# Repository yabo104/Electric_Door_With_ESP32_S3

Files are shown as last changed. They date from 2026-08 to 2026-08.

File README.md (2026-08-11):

# Controlador de Portón — ESP32-S3

Controlador electrónico para automatizar la apertura y cierre de un portón residencial, con
firmware propio (ESP32-S3) y placa controladora diseñada a medida (KiCad).

Mueve el motor mediante dos relevos (sentido) y un TRIAC (potencia, por ángulo de fase
sincronizado al cruce por cero de la red), lee finales de carrera y un sensor de efecto Hall para
detectar movimiento/atasco, y decodifica un control remoto RF 433MHz.

## Estado actual

**Funcional en hardware real** — validado de punta a punta en un portón físico:

- Apertura y cierre con un solo botón del control remoto, con inversión de sentido y detención
  parcial (doble pulsación) para dejar pasar personas o vehículos sin abrir del todo.
- Interlock de seguridad: nunca ambos relevos activos a la vez, el motor siempre se detiene antes
  de invertir sentido.
- Detección de atasco por ausencia de pulsos del sensor de movimiento, con estado de falla y
  reset manual por un botón dedicado.
- Disparo del TRIAC por ángulo de fase, sincronizado al cruce por cero de la red — hoy en un
  **nivel de potencia fijo**, calibrado empíricamente en el portón real (ver *Limitaciones*).
- Indicador LED (encendido en movimiento, parpadeo al confirmar cada final de carrera) y un
  contador de pulsos por trayecto, pensado como base para una futura calibración de recorrido.
- Sin Wi-Fi ni Bluetooth: los dos radios se apagan explícitamente al arrancar.

### Limitaciones conocidas

- **Sin arranque/parada suaves todavía.** El disparo por ángulo de fase está implementado y
  funcionando, pero corre a potencia constante — la rampa gradual (arranque suave) quedó
  pospuesta: en las pruebas, disparar muy cerca del cruce por cero no enganchaba el TRIAC de
  forma confiable con este motor (carga inductiva), y la rampa pasaba por esa zona. La parada
  sigue siendo instantánea.
- El `timeout` de detección de atasco sigue en un valor ajustado empíricamente, no derivado
  analíticamente.
- El diseño de la placa (carpeta de KiCad) está en proceso de renombrado; los archivos de
  fabricación (gerbers/BOM) pueden no reflejar la última revisión del esquemático.

## Estructura del repositorio

- **`Firmware_Porton/`** — firmware, proyecto [PlatformIO](https://platformio.org/) (entorno
  `esp32-s3-devkitc-1`, framework Arduino).
- **`PCB_Door_Controller/`** — diseño de la placa controladora en KiCad.
- **`Docs/`** — datasheets y referencias de los componentes usados (driver TRIAC, convertidor
  DC-DC, módulo de alimentación).
- **`bitacora/`** — documentación de continuidad del proyecto (decisiones, arquitectura,
  histórico de sesiones de desarrollo) bajo el marco [stele](https://github.com/emezav/stele).

## Hardware

| Componente | Detalle |
| --- | --- |
| Módulo | ESP32-S3-WROOM-1U-N8R8 |
| Motor | AC 110V, fase partida (con capacitor de arranque) |
| Potencia | TRIAC BT138-800, disparo por ángulo de fase sincronizado a cruce por cero |
| Sentido | 2 relevos (interlock por software: nunca ambos activos) |
| Posición | 2 finales de carrera (reed switch) + sensor de efecto Hall |
| Control remoto | Receptor RF 433MHz (decodificado externamente, el ESP32-S3 lee canales digitales) |

## Arranque de desarrollo

```bash
cd Firmware_Porton
pio run                              # compilar
pio run -t upload --upload-port COMx # cargar a la placa
pio device monitor -p COMx -b 115200 # monitor serie (o el USB CDC nativo del ESP32-S3)
```

## Licencia

Sin definir todavía.

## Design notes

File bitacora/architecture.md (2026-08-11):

# architecture.md — Firmware_Porton

> Mapa de módulos y **patrones reutilizables** de este producto. Objetivo: que ningún agente
> tenga que releer el fuente para redescubrir un patrón ya entendido. Se **lee** al inicio de
> cualquier sesión que toque esta área y se **actualiza** al cerrar si se descubre un patrón
> nuevo.
>
> Frontera: aquí va *cómo está organizado el producto* (estructura + patrones). Las *trampas
> puntuales* van en `memory.md`; las *decisiones de producto* en `requirements.md`.
>
> Este proyecto tiene dos productos con estructura propia: el firmware (este archivo) y la placa
> controladora en KiCad (`PCB_puerta/` — en proceso de rename, ver `latest.md`).

## Stack

- C++ sobre framework **Arduino**, gestionado con **PlatformIO** (`Firmware_Porton/platformio.ini`).
- Build: `pio run` (desde `Firmware_Porton/`). Carga: `pio run -t upload`. Monitor:
  `pio device monitor -b 115200` (por USB CDC nativo del ESP32-S3, ver `platformio.ini`).

## Estructura de módulos

- `Firmware_Porton/platformio.ini` — entorno `esp32-s3-devkitc-1`, framework `arduino`, USB CDC
  habilitado desde el arranque (`ARDUINO_USB_MODE`/`ARDUINO_USB_CDC_ON_BOOT`).
- `Firmware_Porton/include/porton.h` — pines, tiempos de la máquina de estados (`#define`, todos
  en milisegundos) y prototipos públicos de `porton.cpp`.
- `Firmware_Porton/src/porton.cpp` — toda la lógica: inicialización, interlock de salidas de
  potencia, máquina de estados del portón, y la interfaz de pruebas por `Serial`. El detalle de
  funciones internas (`static`, no expuestas en el header) está comentado en el propio archivo.
- `Firmware_Porton/src/main.cpp` — `setup()`/`loop()`, delgado: inicializa, lee `Serial` si hay
  dato, y llama a `procesarComandoSerial()` + `actualizarEstadoPuerta()` en cada iteración.
- `Firmware_Porton/lib/`, `Firmware_Porton/test/` — carpetas estándar de PlatformIO, vacías por
  ahora.

## Patrones reutilizables ⭐

- **Interlock de salidas de potencia centralizado** — `seleccionarSentido(sentido)` en
  `src/porton.cpp` es el **único** punto del código que escribe `RELAY_OP`/`RELAY_CL`; siempre
  escribe los dos pines juntos, así que "ambos relevos activos a la vez" es estructuralmente
  imposible, no una convención a recordar. `detenerMotor()` corta `TRIGGER` primero y después
  llama a `seleccionarSentido(0)`. **Cualquier código nuevo que necesite mover el motor debe pasar
  por estas dos funciones, nunca por `digitalWrite` directo a los relevos/TRIGGER.**
- **Máquina de estados no bloqueante, con `millis()`** — `actualizarEstadoPuerta()`, sobre el enum
  `EstadoPuerta` (`DETENIDA`, `ABRIENDO`, `CERRANDO`, `ERROR`). Sin `while()`/`delay()` largos: los
  tiempos de asentamiento (`RELAY_SETTLE_MS`), de parada antes de invertir sentido
  (`REVERSE_STOP_MS`) y de timeout de atasco (`ENCODER_TIMEOUT_MS`) se miden comparando
  `millis()` contra un timestamp guardado, nunca bloqueando el `loop()`. Ver `requirements.md` §3.
- **Botón por flanco, no por nivel** — `botonD0Presionado()`/`botonResetPresionado()` solo
  disparan en la transición de no-presionado a presionado (con antirrebote), así que mantener el
  botón apretado no genera comandos repetidos. Cada botón tiene su propio estado de flanco/
  antirrebote — no se comparten, porque son semánticamente independientes (`D0` opera, el reset
  en `D2` solo reconoce una falla) y podrían presionarse casi a la vez.
- **Reset de falla como botón dedicado, no como gesto** — la salida de `ERROR` usa un pin físico
  aparte (`D2`) en vez de una pulsación larga del mismo botón de operar. Más simple de
  implementar (sin temporizar "cuánto es largo") y más seguro: una pulsación normal de `D0` nunca
  puede sacar de `ERROR` por accidente. Ver `requirements.md` §3/§4.
- **Pulsación única vs. doble durante el movimiento** — `manejarPulsacionEnMovimiento()`
  centraliza la decisión: una sola pulsación de `D0` programa una reversa segura (detiene,
  espera `REVERSE_STOP_MS`, invierte); una segunda pulsación dentro de `DOBLE_PULSACION_MS`
  cancela esa reversa y deja el portón donde está (apertura/cierre parcial). Es la misma función
  para los dos casos donde puede llegar la segunda pulsación (todavía en movimiento, o ya
  detenido esperando la reversa) — evita duplicar la lógica de "es doble o no".
- **Interfaz de comandos por Serial** — `procesarComandoSerial()`, un switch sobre caracteres
  ASCII. Reusa `seleccionarSentido()`/`detenerMotor()` en vez de escribir los pines de potencia
  por su cuenta, así el interlock también aplica en modo de prueba manual.
- **Disparo del TRIAC por ángulo de fase, con dos `esp_timer` en cascada** — `isrZcross()` (ISR
  real de `ZCROSS`, con antirrebote) arma `timerDisparo` con el retardo de fase actual
  (`delayDisparoActualUS`); su callback (`onDisparoTriac`) pulsa `TRIGGER` y arma `timerPulso`
  para soltarlo tras `PULSO_TRIAC_US`. Ninguna ISR hace trabajo pesado: solo lee una variable y
  arma un temporizador. `actualizarRampa()` (llamada desde `manejarMovimiento()`, fuera de
  cualquier ISR) es la única que **calcula** el retardo objetivo, interpolando con `millis()` —
  mismo patrón no bloqueante que el resto de la máquina de estados. Ver `requirements.md` §5.
- **Cancelar temporizadores pendientes al detener** — `detenerMotor()` llama `esp_timer_stop()`
  sobre `timerDisparo` antes de forzar `TRIGGER` a `HIGH`, para que no quede un disparo de fase
  ya programado que dispare el gate después de haber decidido parar. Mismo principio que "cortar
  `TRIGGER` antes de liberar los relevos" — parar significa parar todo, no solo la salida visible.
- **Contador de posición relativa (suma/resta según sentido)** — el contador de trayecto
  (`contadorTrayecto`, `requirements.md` §6) no cuenta pulsos crudos: compara el sentido actual
  (`doorStd`) contra el sentido con el que arrancó el trayecto (`sentidoTrayecto`) en cada pulso
  de `isrEncA2()`, sumando si coinciden y restando si no. Es el mismo patrón que usaría cualquier
  odómetro relativo sin posición absoluta — reutilizable si en el futuro hace falta estimar
  posición en otro contexto del proyecto.
- **Máquina de fases para efectos no bloqueantes cortos** — el parpadeo del LED
  (`actualizarParpadeoLed()`, `requirements.md` §7) usa un patrón chico de estados (`0` inactivo,
  `1` pausa, `2` encendido) con su propio timestamp, revisado cada iteración desde
  `actualizarEstadoPuerta()`. Mismo enfoque no bloqueante que el resto del código; sirve de
  plantilla para cualquier otra señal temporizada corta que se necesite más adelante (no hace
  falta un RTOS task ni un `esp_timer` para esto).

## Flujos clave

1. **Arranque:** `main.cpp:setup()` → `inicializarPines()` apaga WiFi/Bluetooth (`apagarRadios()`,
   `requirements.md` §8), deja relevos, `TRIGGER` y `LED` en su estado seguro/apagado, arma las
   interrupciones de encoder (`ENCA` y `ENCA2`, `CHANGE`) y de `ZCROSS` (`RISING`), crea los dos
   `esp_timer` del disparo del TRIAC, y abre `Serial`.
2. **Ciclo principal:** `main.cpp:loop()` → si hay dato en `Serial`, lo guarda en `comando` →
   `procesarComandoSerial()` → `actualizarEstadoPuerta()` (que además revisa el botón de reset y
   el parpadeo del LED en cada vuelta, antes del switch por estado).
3. **Apertura/cierre:** en `DETENIDA`, un flanco de `D0` decide sentido según la posición real
   (`FC_OPEN`/`FC_CLOSE`, o la última llegada confirmada si ninguno está activo —
   `requirements.md` §4) → si el origen es un final de carrera confirmado, arma el contador de
   trayecto (§6) → `iniciarMovimiento()` activa el relevo y enciende el LED fijo → tras
   `RELAY_SETTLE_MS` se habilita el TRIAC a potencia fija (`POTENCIA_MOTOR_PCT`, sin rampa por
   ahora — `requirements.md` §5) → en movimiento se vigilan fin de carrera de destino, timeout de
   encoder (atasco) y un nuevo flanco de `D0` (pide reversa o, si es la segunda pulsación dentro
   de `DOBLE_PULSACION_MS`, detiene y se queda a medio camino) → al llegar al fin de carrera,
   `detenerMotor()` (instantáneo), se guarda la llegada confirmada, se reporta el trayecto si era
   válido, y arranca el parpadeo del LED (§7).
4. **Atasco:** sin pulsos de `ENCA`/`ENCA2` durante `ENCODER_TIMEOUT_MS` con el TRIAC ya activo →
   `detenerMotor()` + `ERROR` (invalida el trayecto en curso). Única salida: un flanco de `D2`,
   que vuelve a `DETENIDA` sin reintento automático (ver `requirements.md` §3).

## Brecha conocida / pendiente

- **Parada suave y arranque suave "de verdad" (con rampa).** El release (sesión 008) corre a
  potencia fija — ver `requirements.md` §5 para el porqué (enganche inconsistente del TRIAC cerca
  del cruce por cero con esta carga inductiva). El código de la rampa
  (`RAMPA_ARRANQUE_MS`/`actualizarRampa()`) sigue en `porton.cpp` sin usar. Retomar ambas cosas
  queda pospuesto a una sesión futura, con calibración de recorrido por conteo de pulsos (§6)
  como paso previo — a especificar por el usuario.
- **`ESP_TIMER_ISR` no disponible en esta build** — los dos `esp_timer` del disparo del TRIAC
  corren en dispatch `ESP_TIMER_TASK` (por defecto), no en una ISR real; puede haber más jitter
  del ideal en el ángulo de disparo. No impidió que el release funcionara en el portón real. Ver
  `memory.md`.

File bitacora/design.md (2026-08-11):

# design.md — Decisiones y principios generales del proyecto

> **Por qué `Controlador_Porton` es como es**, a gran escala. Estable, se lee para orientarse y
> rara vez cambia. Frontera: aquí van *principios y apuestas grandes transversales*; las *specs y
> decisiones por feature* van en `requirements.md`; los *patrones de código* en
> `architecture.md`; las *trampas de código* en `memory.md`. Tope objetivo ~200 líneas: si una
> decisión crece, se extrae a su tema de `requirements.md` y aquí queda 1-3 líneas + link.

## Norte

Controlador electrónico para automatizar la apertura y cierre de un portón, con su propio
firmware y placa controladora diseñada a medida. A futuro, este proyecto forma parte de un pool
de proyectos open-source del usuario, pensados como referencia de trabajos realizados.

## Principios de diseño (no negociables)

- **Un hogar por dato** — cada hecho vive en un solo documento; los demás apuntan.
- **Fail-safe en las salidas de potencia** — relevos y disparo de TRIAC arrancan en `HIGH`
  (desactivados) en `setup()`; ADAPTAR si esto deja de ser cierto al cambiar el hardware.
- ADAPTAR: agregar aquí otros tenets durables (p. ej. tiempos de seguridad, comportamiento ante
  falla de sensor, requisitos normativos si aplica) a medida que se decidan.

## Restricciones y no-negociables

- **Wi-Fi y Bluetooth apagados activamente** (`apagarRadios()`, sesión 008) — el ESP32-S3 los
  tiene disponibles pero el proyecto no los usa; se descartó además un modo de bajo consumo
  (deep sleep) para ahorrar energía/calor, porque el equipo está alimentado de red, no a batería
  (detalle en Decisiones estructurales más abajo). A futuro: Bluetooth para controlar el portón
  desde una app móvil (no hay diseño de ese protocolo todavía — cuando se aborde, hay que volver
  a habilitar el radio explícitamente, y documentar el protocolo en `requirements.md`).
- **Idioma de la documentación (decisión del usuario, sesión 005):** durante el desarrollo activo
  se mantiene en español (es lo que ya hay y lo que configura `stele.config.md`). **Cuando el
  proyecto se dé por terminado**, se traduce todo a inglés, porque el destino es un pool de
  proyectos open-source de referencia. No es un cambio a aplicar ahora — es una tarea de cierre
  de proyecto (traducir `bitacora/`, comentarios de código, `README` si se agrega uno, etc.),
  a recordar cuando se llegue a esa etapa.
- ADAPTAR: agregar otros límites (normativos, presupuesto, requisitos de seguridad eléctrica al
  operar TRIAC/relevos de línea) a medida que se decidan.

## Decisiones estructurales (ADR-lite)

> Decisiones grandes y transversales. Formato corto y fechado; el detalle va a `requirements.md`.

### 2026-08-07 — Firmware migrado de sketch `.ino` a proyecto PlatformIO

- **Contexto:** el firmware vivía como un único `Firmware_Porton.ino` (Arduino IDE), sin
  separación entre inicialización, lógica de puerta y manejo de comandos.
- **Decisión:** reestructurar `Firmware_Porton/` como proyecto PlatformIO (`platformio.ini`,
  `src/main.cpp`, `src/porton.cpp`, `include/porton.h`), entorno `esp32-s3-devkitc-1`.
- **Alternativas descartadas:** mantener el `.ino` (Arduino IDE) — descartado porque el proyecto
  pasa a usar PlatformIO como herramienta de build/flash a partir de ahora.
- **Consecuencias / detalle:** ver `architecture.md`.

### 2026-08-08 — Máquina de estados del portón: interlock de seguridad + no bloqueante

- **Contexto:** el firmware original (plantilla de pruebas) no garantizaba por diseño que los dos
  relevos nunca estuvieran activos juntos, invertía sentido con `delay()` bloqueantes, y no tenía
  forma de detectar un atasco del motor.
- **Decisión:** interlock de relevos centralizado en una sola función (`seleccionarSentido()`,
  ver `architecture.md`), máquina de estados no bloqueante basada en `millis()`, y detección de
  atasco por timeout de pulsos del encoder (`ENCA` por interrupción). El TRIAC se trata como
  interruptor todo/nada (sin `ZCROSS`) hasta una sesión futura. Detalle en `requirements.md` §3/§4.
- **Alternativas descartadas:** mantener el diseño con `while()`/`delay()` bloqueantes — se
  descartó porque impide medir timeouts (atasco) y responder a `Serial` mientras la puerta se
  mueve.
- **Consecuencias / detalle:** ver `architecture.md` → Patrones reutilizables y Brecha conocida.

### 2026-08-08 — Validación en hardware real: control remoto D0/D2 y recuperación de ERROR

- **Contexto:** primera sesión con la placa física conectada. Se confirmó en hardware que abrir/
  cerrar, finales de carrera, interlock de relevos, TRIAC a máxima potencia y detección de atasco
  funcionan. Aparecieron dos problemas de hardware (no de firmware): `ENCA`/`ENCB` con pull-ups
  defectuosos, y el conteo de `ZCROSS` con ruido de umbral (parcialmente corregido por software).
  El usuario pidió además: separar el botón de operar del de reset de falla, una forma de detener
  el portón a medio camino (apertura parcial para personas/motos), y una política de salida de
  `ERROR`.
- **Decisión:** `D0` concentra todo el control normal (abrir/cerrar/invertir/detener parcial);
  `D2` es un botón dedicado, exclusivo, para salir de `ERROR` — nunca reintento automático tras
  un atasco (mismo criterio que UL 325 para fallas de obstrucción: la salida de una falla es una
  acción humana deliberada). Detección de atasco migrada a `ENCA2` (sensor Hall en `GPIO44`),
  confirmada limpia en banco, en paralelo con `ENCA` por si se repara. Detalle completo en
  `requirements.md` §3/§4, patrones en `architecture.md`.
- **Alternativas descartadas:** pulsación larga del mismo botón (`D0`) para resetear `ERROR` — se
  descartó por un botón dedicado (`D2`): más simple de implementar y evita que una pulsación
  normal saque de `ERROR` por accidente. Reversa automática alejándose de la obstrucción al
  entrar en `ERROR` — se descartó por ahora: sin sensor de obstrucción dedicado, no hay forma de
  saber hacia dónde es seguro moverse.
- **Consecuencias / detalle:** ver `requirements.md` §3/§4 y `architecture.md`.

### 2026-08-08 — Arranque suave del TRIAC: alcance acotado a solo arranque

- **Contexto:** el portón toma velocidad y golpea fuerte contra el tope al cerrar, con riesgo
  para los engranajes. El usuario pidió arranque y parada suaves por ángulo de fase del TRIAC.
  Antes de tocar código se armó un plan (vía plan mode) y se lo discutió con el usuario.
- **Decisión:** acotar esta ronda a **solo arranque suave**, para validar primero si el mecanismo
  de disparo por fase regula bien la potencia real (confirmado el TRIAC: `BT138-800`, pulso de
  gate de 200us). La parada sigue siendo instantánea. Parada suave con zona de desaceleración
  necesita conteo de pulsos de recorrido completo y un modo de calibración — el usuario lo va a
  especificar en una sesión futura, no se improvisa ahora. Detalle en `requirements.md` §5.
- **Alternativas descartadas:** implementar arranque y parada juntos en la misma ronda — se
  descartó porque la parada depende de una pieza no diseñada todavía (calibración de recorrido
  por pulsos de `ENCA2`, con un solo canal de encoder — no hay dirección, solo conteo).
- **Estado al cierre de la sesión 007:** implementado y subido a la placa, pero **sin confirmar
  que el arranque suave se perciba en el motor real** — el usuario no notó diferencia en la
  primera prueba. Pendiente diagnóstico con osciloscopio (sesión futura) antes de dar la
  funcionalidad por buena. Ver `requirements.md` §5 y `memory.md` para el detalle técnico y las
  dos hipótesis abiertas (bug vs. limitación física del motor de inducción).
- **Consecuencias / detalle:** ver `requirements.md` §5 y `architecture.md`.

### 2026-08-11 — TRIAC: release en potencia fija; posición inferida por última llegada confirmada

- **Contexto:** sesión larga de pruebas en el portón físico real (no solo el motor en banco).
  Salieron a la luz dos problemas que la sesión 007 no había podido ver: (1) la rampa de arranque
  suave pasaba por ángulos de disparo cercanos al cruce por cero donde el TRIAC no engancha de
  forma confiable con esta carga inductiva, generando paradas falsas por "atasco"; (2) por
  inercia del motor, el imán de un fin de carrera puede rebasar el sensor al frenar, dejando
  momentáneamente "ningún fin de carrera activo" aunque el portón esté efectivamente en esa
  posición — el firmware volvía a intentar moverse hacia el mismo tope.
- **Decisión:** cerrar el release con el TRIAC en **potencia fija** (85%, calibrada probando
  varios niveles en el portón real — ver `requirements.md` §5), la rampa de arranque suave
  pospuesta. Y agregar `ultimaLlegadaConfirmada`: cuando ningún fin de carrera está activo, el
  sentido se decide contra la última llegada confirmada de verdad, no siempre "cierra por
  defecto" (`requirements.md` §4). También se agregaron, a pedido del usuario: contador de
  trayecto por pulsos de `ENCA2` (§6, para datos de una futura calibración de recorrido) e
  indicador LED (§7, pensado para la instalación final sin acceso al Serial).
- **Alternativas descartadas:** insistir con la rampa ajustando solo los tiempos — se descartó
  porque el problema no era de tiempos sino de que la rampa pasaba por una zona de disparo donde
  el TRIAC no engancha bien; había que resolver eso primero (queda como base para retomar la
  rampa más adelante).
- **Consecuencias / detalle:** ver `requirements.md` §4/§5/§6/§7, patrones en `architecture.md`,
  hallazgos técnicos en `memory.md`.

(Repetir por decisión. Las que dejan de ser relevantes se podan; su rastro queda en el historial.)

## Glosario

- **Portón** — la puerta/reja automatizada que controla este sistema.
- **FC_OPEN / FC_CLOSE** — finales de carrera (reed switch) que indican portón totalmente abierto
  / cerrado.
- **D0-D3** — canales ya decodificados del receptor RF 433MHz de los controles remotos. `D0` =
  control normal (abrir/cerrar/invertir/detener parcial); `D2` = reset de `ERROR` únicamente;
  `D1`/`D3` sin rol asignado.
- **TRIGGER** — señal de disparo del TRIAC, sincronizada con `ZCROSS` (cruce por cero de la AC)
  por ángulo de fase. **Release actual:** ángulo fijo (potencia constante, sin rampa) — ver
  `requirements.md` §5. El TRIAC regula la **potencia** entregada al motor; no decide el sentido
  de giro (eso lo hacen los relevos).
- **RELAY_OP / RELAY_CL** — relevos que eligen el **sentido** de giro del motor (qué terminal de
  control queda energizado), no la potencia.
- **Motor de fase partida (110VAC)** — motor con un terminal común y dos terminales de control,
  con un capacitor (33µF/400V) entre ambos que produce el desfase necesario para girar en un
  sentido u otro según cuál terminal se energiza.
- **ENCA / ENCB** — canales en cuadratura del encoder del motor. Tienen un problema real de
  hardware (pull-up del circuito de entrada) y hoy no aportan pulsos.
- **ENCA2** — sensor de efecto Hall alternativo (`GPIO44`), confirmado funcionando en banco: es
  la fuente real de detección de atasco hoy, en paralelo con `ENCA` por si se repara. También
  alimenta el contador de trayecto (`requirements.md` §6).
- **Última llegada confirmada** — el último fin de carrera que el firmware vio activarse de
  verdad (no inferido). Decide el sentido del próximo movimiento cuando ningún fin de carrera
  está activo en el momento de la pulsación (`requirements.md` §4).
- ADAPTAR: agregar términos de dominio adicionales según surjan (p. ej. nombre/modelo del
  operador de portón, protocolo del control remoto).

## Mapa de documentación

Dónde vive cada tipo de información: ver `AGENTS.md` → "Dónde vive cada cosa" (no duplicar aquí).

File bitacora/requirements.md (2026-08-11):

# requirements.md — Qué hace el producto (specs, contratos, decisiones por feature)

> **Fuente de verdad del producto**: specs, contratos de API, modelo de datos, decisiones por
> feature, contexto de negocio detallado. Es lo que perdura y comparten todos los agentes y
> sesiones. Frontera: los *principios y apuestas grandes transversales* van en `design.md`; los
> *patrones de código* en `architecture.md`; las *trampas de código* en `memory.md`.
>
> **Estructura:** una sección `§` por decisión o feature, **autocontenida**. Este archivo se lee
> con `grep` y por rango, nunca entero. **Umbral de extracción: ~50 líneas** — por encima, la
> decisión se mueve a `bitacora/temas/<TEMA>.md` y aquí queda un resumen de 2-3 líneas + link.

## Cómo usar este archivo

- **Antes de implementar**, `grep -n` la sección relevante y lee solo esa parte.
- **Toda decisión** de producto/arquitectura/integración/negocio que deba perdurar se documenta
  aquí *en el momento en que se toma*.

## § Índice de decisiones

- §1 — Interfaz de comandos por Serial (pruebas de banco)
- §2 — Contrato de hardware: sistema de potencia y pines ESP32-S3
- §3 — Máquina de estados del portón (segura, no bloqueante)
- §4 — Política del control remoto (D0/D1)
- §5 — Disparo del TRIAC por ángulo de fase (release: potencia fija, sin rampa)
- §6 — Contador de trayecto (pulsos de `ENCA2`)
- §7 — Indicador LED
- §8 — Radios WiFi/Bluetooth apagadas (sin deep sleep)

### §1 — Interfaz de comandos por Serial (pruebas de banco)

- **Contrato:** `Firmware_Porton` expone por `Serial` (USB CDC nativo del ESP32-S3, 115200
  baudios) una interfaz de un solo carácter para pruebas manuales, manejada en
  `procesarComandoSerial()` (`Firmware_Porton/src/porton.cpp`):
  - `0` — parpadea el LED.
  - `1` — activa el relevo de apertura, **sin habilitar el TRIAC** (no mueve el motor).
  - `2` — activa el relevo de cierre, **sin habilitar el TRIAC**.
  - `3` — detiene todo (relevos + TRIAC), vía la misma función `detenerMotor()` que usa la
    máquina de estados.
  - `4` — imprime por Serial el estado de las entradas `D0`-`D3`.
  - `5` — fuerza `TRIGGER` en `HIGH` (TRIAC apagado).
  - `6` — fuerza `TRIGGER` en `LOW` (TRIAC encendido, máxima potencia).
  - `7` — limpia el comando pendiente (no-op).
  - Los comandos `1`/`2` reusan `seleccionarSentido()`, la misma función que usa la máquina de
    estados automática — así el interlock de "nunca ambos relevos activos" aplica también en modo
    de prueba manual.
  - Esta interfaz **no** reemplaza a la máquina de estados de la puerta (`actualizarEstadoPuerta()`),
    que corre en paralelo cada iteración del `loop()`. Si se usan comandos manuales mientras la
    puerta está en movimiento automático, pueden interferir entre sí (es una interfaz de banco,
    no pensada para correr junto con operación autónoma).
- **Por qué:** pensada para validar cableado/hardware de banco antes de operar el portón de forma
  autónoma. No es un protocolo pensado para integrarse con otro sistema.

### §2 — Contrato de hardware: sistema de potencia y pines ESP32-S3

- **Qué es:** motor AC 110V de fase partida (común + 2 terminales de control + capacitor 33µF/
  400V entre ellos), 2 relevos que eligen el sentido, 1 TRIAC que regula la potencia (sincronizado
  a `ZCROSS`), encoder de 2 canales para detectar movimiento/dirección, 2 finales de carrera *reed
  switch*, receptor RF 433MHz que expone 4 canales digitales (`D0`-`D3`). Tabla completa de pines
  ESP32-S3 con tipo/polaridad de cada señal.
- **Por qué se extrajo:** contrato largo (tabla de 13 pines + descripción de sistema) y es la
  referencia autoritativa antes de escribir cualquier lógica de firmware nueva.
- Detalle completo, con la brecha entre este contrato y lo que el firmware actual ya implementa:
  [`bitacora/temas/hardware-esp32-s3.md`](./temas/hardware-esp32-s3.md).

### §3 — Máquina de estados del portón (segura, no bloqueante)

- **Estados** (`EstadoPuerta` en `include/porton.h`): `DETENIDA`, `ABRIENDO`, `CERRANDO`, `ERROR`.
  Reemplaza al diseño anterior (`STOP`/`WAITING` separados) — `DETENIDA` cubre tanto el arranque
  como el reposo entre movimientos.
- **Reglas de seguridad no negociables** (pedidas por el usuario, sesión 004):
  1. **Nunca ambos relevos activos a la vez.** Se garantiza por construcción:
     `seleccionarSentido()` escribe siempre los dos pines juntos (uno `LOW`, el otro `HIGH`, o los
     dos `HIGH`); ningún otro punto del código escribe `RELAY_OP`/`RELAY_CL` por separado.
  2. **El motor se detiene ante cualquier cambio de sentido** — nunca se invierte "en caliente".
     Al detectar un pedido de reversa en movimiento, se llama `detenerMotor()` (corta `TRIGGER`
     primero, después libera los relevos) y se guarda el sentido pedido en `sentidoPendiente`; el
     nuevo sentido recién arranca tras `REVERSE_STOP_MS` (500 ms) detenido.
  3. **La potencia (TRIAC) se habilita después del relevo**, no junto con él:
     `RELAY_SETTLE_MS` (100 ms) entre elegir sentido y encender `TRIGGER`. Evita conmutar el
     relevo con el motor ya energizado.
- **TRIAC con disparo por ángulo de fase, sincronizado a `ZCROSS`, desde la sesión 007** — ver §5.
  Reemplaza al diseño anterior (interruptor todo/nada).
- **Detección de atasco vía encoder — confirmada en hardware real (sesión 006):** una
  interrupción actualiza un timestamp (`ultimoPulsoEncoderISR`); si el TRIAC lleva más de
  `ENCODER_TIMEOUT_MS` (2000 ms — ajustado varias veces por el usuario durante las pruebas de la
  sesión 008 en el portón real; sigue marcado `TEMPORAL` en el código, no hay un valor "final"
  derivado analíticamente) activo sin ningún pulso, se detiene el motor y se pasa a `ERROR`. Dos
  fuentes en paralelo alimentan el mismo timestamp: `ENCA` (con un problema de hardware conocido —
  pull-up del circuito de entrada — hoy no aporta pulsos) y `ENCA2`, un sensor Hall en `GPIO44`
  que sí funciona (confirmado: 0 pulsos con el motor quieto, pulsos reales con el motor girando).
  Si se arregla el hardware de `ENCA`, vuelve a sumar sin más cambios de código.
- **Salida de `ERROR` — implementada y confirmada en hardware real (sesión 006):** botón
  dedicado (`D2`, ver §4) saca de `ERROR` y vuelve a `DETENIDA` "como recién arrancado" — el
  siguiente `D0` decide el sentido por la posición real de los finales de carrera. **Sin
  reintento automático**, a propósito: un atasco puede ser una obstrucción real, y reintentar
  por temporizador movería el motor otra vez sin que nadie lo haya verificado (mismo criterio
  que usan los estándares de portones automáticos tipo UL 325 para fallas de obstrucción). Una
  reversa automática alejándose de la obstrucción queda como posible mejora futura, pospuesta
  hasta tener un sensor de obstrucción dedicado.
- **No bloqueante:** se eliminaron los `while()`/`delay()` largos que había en el diseño anterior
  dentro de la máquina de estados (bloqueaban `loop()` y hubieran roto el timeout de atasco). Los
  tiempos (`RELAY_SETTLE_MS`, `REVERSE_STOP_MS`, `ENCODER_TIMEOUT_MS`) se miden con `millis()`
  sin bloquear.

### §4 — Política del control remoto (D0 mueve, D2 resetea fallas)

> Confirmado en hardware real, sesión 006. `D1`/`D3` están cableados en la tarjeta pero sin rol
> asignado por ahora.

- **`D0` — control normal (abrir/cerrar/invertir/detener parcial).** Detección por flanco, no
  por nivel: un botón mantenido presionado genera un solo comando, no uno por iteración del
  `loop()`. Con antirrebote (`BOTON_DEBOUNCE_MS`, 80 ms).
  - **El sentido se decide por la posición real** (finales de carrera), no por el último
    movimiento hecho: portón en el fin de carrera de **abierto** → `D0` **cierra**; en el de
    **cerrado** → `D0` **abre**. Se evalúa en cada pulsación, no solo al arrancar.
  - **Posición intermedia (ningún fin de carrera activo) — corregido en la sesión 008:** ya no
    es siempre "por defecto cierra". El firmware recuerda la última llegada **confirmada**
    (`ultimaLlegadaConfirmada`, en `porton.cpp`) y decide el sentido contrario a esa. Esto cubre
    un caso real encontrado en el portón físico: por inercia del motor, el imán del fin de
    carrera puede rebasar el sensor al frenar, y el switch se desactiva de nuevo justo después de
    haber llegado — sin este ajuste, el firmware volvía a intentar cerrar (o abrir) contra el
    tope mecánico ya alcanzado. Solo si **nunca** hubo una llegada confirmada (arranque en frío,
    posición realmente desconocida) se usa el default original: cierra.
  - **Una pulsación de `D0` durante el movimiento invierte el sentido** — nunca en caliente:
    detiene, espera `REVERSE_STOP_MS` (500 ms), recién ahí arranca en el sentido contrario.
  - **Dos pulsaciones de `D0` dentro de `DOBLE_PULSACION_MS` (2000 ms) durante el movimiento:
    detiene y se queda a medio camino, sin invertir.** Pensado para apertura/cierre parcial (dejar
    pasar una persona o una moto sin abrir del todo). Implementado en
    `manejarPulsacionEnMovimiento()` — una segunda pulsación que caiga dentro de la ventana de
    `REVERSE_STOP_MS` (mientras espera para iniciar la reversa) también cuenta como "doble".
- **`D2` — reset manual de `ERROR` únicamente.** No mueve el portón. Ver §3 para la política de
  por qué no hay reintento automático tras un atasco.
- **`D1`/`D3` sin uso.** Se leen igualmente en el comando de prueba `4` (`requirements.md` §1)
  pero no participan de la lógica automática.

### §5 — Disparo del TRIAC por ángulo de fase (release: potencia fija, sin rampa)

> Mecanismo implementado en la sesión 007 (plan discutido y aprobado con el usuario antes de tocar
> código). **Motivo original:** el portón tomaba velocidad y golpeaba fuerte contra el tope al
> cerrar, con riesgo de dañar los engranajes. **Decisión de alcance para el release (sesión 008,
> con el usuario):** dejar el TRIAC en **potencia fija** (sin la rampa de arranque suave) — ver el
> porqué más abajo.

- **Mecanismo (sin cambios desde la sesión 007):** `ZCROSS` es una interrupción real (no solo
  diagnóstico). En cada cruce por cero válido (con antirrebote, `ZCROSS_DEBOUNCE_US`), si el TRIAC
  está activo, arma un `esp_timer` con el retardo de fase actual (`delayDisparoActualUS`); al
  vencer, pulsa `TRIGGER` (gate del TRIAC `BT138-800`) por `PULSO_TRIAC_US` con un segundo
  `esp_timer`. `PULSO_TRIAC_US` subió de 200 a 500µs en la sesión 008: un pulso más largo ayuda a
  enganchar con esta carga inductiva.
- **La rampa de arranque suave (interpolar `DISPARO_US_MIN` → `DISPARO_US_MAX` durante
  `RAMPA_ARRANQUE_MS`) quedó DESACTIVADA para el release.** Motivo, encontrado en pruebas en banco
  con el portón real (sesión 008): disparar demasiado cerca del cruce por cero (potencias
  cercanas al 100%) no siempre engancha el TRIAC con esta carga inductiva — al 100% exacto
  (~6,5° desde el cruce) el motor directamente no se movía. La rampa original pasaba por esa zona
  marginal al principio de cada arranque, y eso generaba paradas falsas por "atasco" (§3): el
  enganche inconsistente ciclo a ciclo genera pulsos de torque irregulares, no una rampa suave de
  potencia creciente.
- **Solución para el release: potencia fija, calibrada empíricamente.** `POTENCIA_MOTOR_PCT` (hoy
  85%, en `porton.h`) fija `DISPARO_US_MIN = DISPARO_US_MAX` — el TRIAC dispara al mismo ángulo de
  fase durante todo el movimiento, sin rampa. Es una interpolación **lineal en tiempo** entre
  `DISPARO_US_MAX` (100%) y `SEMICICLO_US` (0%), no un porcentaje exacto de potencia RMS (esa
  relación es curva), pero sirve como perilla monótona para ajustar a mano si hace falta.
  Historial de pruebas que llevaron al 85%: 100% no movía el motor; 90% y 95% sí lo movían pero
  daban `ERROR` falso en tramos del recorrido con más esfuerzo mecánico; 85% (con el pulso de gate
  ya en 500µs) fue el primer nivel que movió el portón de punta a punta sin falsos atascos.
- **La parada sigue siendo instantánea** — sin rampa de bajada, sin cambios en esta sesión.
- **Arranque suave real (con rampa) queda pospuesto**, ahora con un piso de potencia fiable
  (85%, pulso de 500µs) como punto de partida en vez de los valores originales sin probar. El
  código de la rampa (`RAMPA_ARRANQUE_MS`, `actualizarRampa()`) se deja en `porton.cpp` sin usar,
  para no rehacerlo desde cero cuando se retome.
- **Detalle de hallazgos técnicos y gotchas de esta implementación:** `memory.md`.

### §6 — Contador de trayecto (pulsos de `ENCA2`)

> Agregado en la sesión 008 a pedido del usuario, para poder revisar si el recorrido completo del
> portón da una cantidad de pulsos de `ENCA2` medianamente consistente entre corridas — dato de
> entrada para una futura calibración de recorrido (parada suave con zona de desaceleración,
> pospuesta, ver §5).

- **Solo es válido entre dos finales de carrera confirmados.** Arranca en 0 únicamente cuando un
  movimiento empieza con un fin de carrera activo en el origen (abierta→cierra o cerrada→abre) —
  **no** desde una posición intermedia (incluida la inferida por `ultimaLlegadaConfirmada`, §4):
  ahí no hay un punto de partida medido, solo asumido, y contaminaría la comparación entre
  corridas.
- **Suma en el sentido del trayecto, resta en el sentido contrario.** Cada pulso de `ENCA2`
  incrementa el contador si el sentido actual coincide con el que tenía el trayecto al arrancar, y
  lo decrementa si no (hubo una reversa) — así el contador siempre refleja la distancia neta
  recorrida desde el origen confirmado, aunque haya idas y vueltas en el medio.
- **Se invalida en silencio (decisión del usuario) si el trayecto se interrumpe** antes de llegar
  al destino: detenido parcial (doble pulsación) o `ERROR` (atasco). No se imprime nada — solo se
  reportan los recorridos completos, que son el dato comparable.
- **Al llegar al fin de carrera de destino**, si el trayecto era válido, imprime por Serial
  `[TRAYECTO] completo, sentido=…, pulsos=…`.

### §7 — Indicador LED

> Agregado en la sesión 008 a pedido del usuario, pensando en la instalación final del portón
> (sin acceso directo al Serial).

- **Encendido fijo mientras el motor está en movimiento** (`ABRIENDO`/`CERRANDO`), apagado el
  resto del tiempo — centralizado en `iniciarMovimiento()`/`detenerMotor()`, no hay otro punto del
  código que escriba `LED` para la operación automática.
- **Parpadeo al detectar el fin de carrera de destino** (confirma que se detectó el imán) —
  **no** en detenido parcial ni en `ERROR`, para no dar una señal engañosa. Secuencia de dos fases,
  no bloqueante: pausa apagada (`LED_PAUSA_PARPADEO_MS`, 100ms) y luego encendido
  (`LED_PARPADEO_MS`, 150ms). La pausa es necesaria: sin ella, el parpadeo arranca desde el mismo
  "encendido" que ya tenía por el movimiento, y el flanco no se distingue a simple vista (bug
  real encontrado en la primera versión, sesión 008).
- **Prioridad estricta:** siempre se llama primero a `detenerMotor()` (corte de salidas,
  instantáneo) y recién después se dispara el parpadeo — nunca al revés.

### §8 — Radios WiFi/Bluetooth apagadas (sin deep sleep)

> Decisión de la sesión 008, a partir de una pregunta del usuario sobre bajo consumo/calor del
> ESP32-S3. Detalle completo de la discusión en `design.md` → Decisiones estructurales.

- **`WiFi.mode(WIFI_OFF)` + `btStop()`** en `inicializarPines()` (`apagarRadios()`,
  `porton.cpp`) — el proyecto no usa ninguno de los dos radios, así que apagarlos evita consumo/
  calor/interferencia sin costo funcional.
- **Se descartó el deep sleep** (que el usuario planteó primero) porque este equipo está
  alimentado de red, no a batería — el ahorro de energía no justifica el costo: perder toda la
  RAM en cada ciclo de sueño (hay que reconstruir el estado desde memoria RTC), la latencia de
  arranque en frío en cada despertar, que el USB CDC (el `Serial` que se usó para depurar toda
  esta sesión) se cae mientras duerme, y verificar con osciloscopio que los relevos/TRIAC no
  flotan durante la transición de sueño/despertar antes de confiar en él con 110VAC de por medio.
- **Costo de la librería WiFi:** aunque solo se llama para apagarla, enlazarla infla el binario
  notablemente (Flash ~8%→20%, RAM ~6%→13% en esta build) — sigue sobrando margen de sobra, pero
  vale la pena saberlo si en el futuro el espacio se vuelve ajustado.

## Modelo de datos

ADAPTAR: no aplica lógica de datos persistentes todavía; el firmware es puramente reactivo sobre
entradas digitales. Si se agrega persistencia (p. ej. posición del portón, configuración por
NVS/EEPROM), documentar aquí el modelo.

## Contratos de API / integración

ADAPTAR: hoy no hay integración de red (Wi-Fi/BLE/MQTT, etc.). Si se agrega, documentar aquí el
contrato (endpoints, payloads, autenticación).

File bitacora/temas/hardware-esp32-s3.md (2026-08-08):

# Tema: Contrato de hardware — sistema de potencia y pines ESP32-S3

> Extraído de `requirements.md` §2 (superó el umbral de ~50 líneas). Fuente: descripción del
> usuario, sesión `003` (`2026-08-08`). Es el **contrato autoritativo** de qué hace cada pin y
> cómo está compuesto el sistema de potencia — el firmware debe respetarlo.

## Sistema de potencia (motor del portón)

- **Motor AC de 110V, fase partida, un solo motor.** Tres terminales: uno **común** y dos de
  **control de giro** (uno por sentido). Entre los dos terminales de control hay un
  **capacitor de arranque/marcha de 33 µF / 400 V** — es lo que da el desfase para que el motor
  gire en un sentido u otro según cuál terminal de control se energiza.
- **Dos relevos (`RELAY_OP`, `RELAY_CL`) conmutan cuál terminal de control queda activo** — deciden
  el **sentido** de giro (abrir/cerrar), no la potencia entregada.
- **Un TRIAC regula la potencia** entregada al motor (fase controlada, sincronizada con el cruce
  por cero de la AC vía `ZCROSS`). Es el elemento que controla **cuánta** potencia recibe el
  motor (p. ej. arranque suave, limitar torque), independiente del sentido que ya fijaron los
  relevos.
- **Encoder de dos canales (`ENCA`, `ENCB`) en el eje del motor** — pulsos en cuadratura: permiten
  saber si el motor **está girando o no**, y en qué **dirección** (por el desfase entre A y B).
  Es la única realimentación de movimiento real (sin él, el firmware no puede distinguir "el
  relevo está activado" de "el motor efectivamente se está moviendo").
- **Dos finales de carrera tipo *reed switch*** (`FC_OPEN`, `FC_CLOSE`) — un imán solidario a la
  parte móvil acciona el reed switch correspondiente al llegar a cada extremo del recorrido.
- **Receptor RF 433 MHz** para los controles remotos — decodifica la señal de aire y expone el
  resultado como hasta 4 líneas digitales (`D0`-`D3`) hacia el ESP32-S3; el ESP32-S3 no decodifica
  RF directamente, solo lee esas salidas ya decodificadas.

## Pines ESP32-S3 (contrato)

| GPIO | Nombre | Tipo | Descripción |
| --- | --- | --- | --- |
| 2 | `LED` | Salida / digital | LED piloto. **Activo en `LOW`** (nivel 0 = encendido). |
| 3 | `ZCROSS` | Entrada / interrupción | Cruce por cero de la AC: pulso en **alto** en cada cruce. Pensado para disparar por interrupción, no por polling (es una señal de temporización). |
| 9 | `D3` | Entrada / digital / RF | Canal decodificado del receptor RF. Activo en **alto**. |
| 10 | `D2` | Entrada / digital / RF | Ídem. |
| 11 | `D1` | Entrada / digital / RF | Ídem. |
| 12 | `D0` | Entrada / digital / RF | Ídem. |
| 13 | `ENCA` | Entrada / interrupción / encoder | Canal A del encoder de movimiento del motor. |
| 14 | `ENCB` | Entrada / interrupción / encoder | Canal B del encoder de movimiento del motor. |
| 15 | `FC_OPEN` | Entrada / interrupción / final de carrera | **Normalmente en alto**; flanco de bajada cuando el imán llega (portón abierto). |
| 16 | `FC_CLOSE` | Entrada / interrupción / final de carrera | **Normalmente en alto**; flanco de bajada cuando el imán llega (portón cerrado). |
| 21 | `TRIGGER` | Salida / digital / disparo TRIAC | Dispara el TRIAC con nivel **bajo**. |
| 38 | `RELAY_OP` | Salida / digital | Activa el relevo de apertura con nivel **bajo**. |
| 39 | `RELAY_CL` | Salida / digital | Activa el relevo de cierre con nivel **bajo**. |

## Consistencia con el firmware actual (`Firmware_Porton/`)

Confirmado contra `include/porton.h` / `src/porton.cpp`:

- Polaridades activas en `LOW` de `RELAY_OP`, `RELAY_CL`, `TRIGGER`, y activo en alto de `D0`-`D3`
  y de los finales de carrera vía `INPUT_PULLUP` (`!digitalRead(FC_OPEN)` = detectado) — **ya
  coinciden** con el código existente.
- **Nuevo dato, no reflejado aún en el firmware:** polaridad de `LED` (activo en `LOW`) — el
  código actual ya arranca en `HIGH` (apagado) en `inicializarPines()`, consistente por
  casualidad de diseño, no porque el firmware lo supiera documentado.
- **Brecha real:** `ZCROSS`, `ENCA`/`ENCB` y `FC_OPEN`/`FC_CLOSE` están pensados como fuentes de
  **interrupción**, pero el firmware actual solo hace `pinMode(..., INPUT[_PULLUP])` y lee
  `FC_OPEN`/`FC_CLOSE` por *polling* dentro de `actualizarEstadoPuerta()`. `ZCROSS` no se usa en
  absoluto todavía (no hay disparo de TRIAC sincronizado a cruce por cero: los comandos `5`/`6` de
  prueba fuerzan `TRIGGER` a mano). `ENCA`/`ENCB` tampoco se leen en ningún lado (estaban
  comentados en el `.ino` original). Ver preguntas de diseño abiertas en `design.md` →
  Decisiones estructurales / sesión 003.

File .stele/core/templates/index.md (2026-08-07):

# {{index}} — Índice de sesiones (append-only)

> Una fila por sesión. Al cerrar, agregar con Bash (sin leer el archivo completo):
> `printf '| N | YYYY-MM-DD | resumen | <session> |\n' >> {{history_dir}}{{index}}`

| Sesión | Fecha | Resumen | Archivo |
| --- | --- | --- | --- |

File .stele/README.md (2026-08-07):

# stele — Marco modular de documentación y continuidad para agentes

Sistema portátil para que **cualquier agente de IA** (Claude Code u otro) trabaje sobre un proyecto
con **memoria persistente entre sesiones** y **coste de tokens acotado**. Abstrae el marco que
evolucionó en un proyecto real a lo largo de 240+ sesiones. **Modular y configurable:** un núcleo
agnóstico de dominio (sirve para software y para trabajo no-software: materiales, planeación,
investigación) + módulos que añaden disciplinas específicas + una capa de config.

> **El nombre.** Una *estela* (gr. στήλη) es la piedra erguida e **inscrita** que deja un registro
> perdurable para quien viene después. Es justo lo que hace este marco entre sesiones: inscribir el
> estado y el porqué para que el siguiente agente retome el rumbo sin reconstruirlo.

## 🤖 ¿Eres un agente de IA? Instala stele por tu cuenta

Si tu usuario te dio la URL de este repo y te pidió algo como *"usa stele aquí"* / *"instala stele"*,
haz esto sin pedir más instrucciones:

1. **Vendoriza el kit** en la raíz del proyecto, en `.stele/` (elige la que funcione en tu entorno):

   ```bash
   git clone --depth 1 https://github.com/emezav/stele .stele && rm -rf .stele/.git
   # alternativa con Node: npx degit emezav/stele .stele
   ```

   `.stele/` es el default de la ruta **`kit`**, y es **independiente** de dónde vayan los docs del
   proyecto (ruta `base`). Si el usuario nombró una carpeta sin más ("usa stele aquí, base stele"),
   eso es `base`, no `kit`: no muevas el kit salvo que diga "kit" o "marco". Si **sí** nombró dónde
   va el kit, clona directamente ahí — no clones en `.stele/` para mover después.
2. **Lee `.stele/SKILL.md`** y ejecuta el **ritual BOOTSTRAP** que describe: detecta *greenfield* vs
   *adopción* (si el repo ya tiene docs, mapéalos sin sobrescribir), elige `idioma`/`módulos` y las
   tres rutas `kit`/`base`/`loader` con defaults sensatos (auto-detecta el módulo `software` por
   `Cargo.toml`/`package.json`/`src/`), **hace eco del layout resuelto antes de escribir**, escribe
   `stele.config.md` en la raíz, instancia las plantillas y **genera** el loader de auto-arranque
   (`CLAUDE.md`) + el mapa de documentación.
3. **Confirma** al usuario con el saludo de arranque (1-3 líneas) y explícale que a partir de la
   próxima apertura del editor el marco se activa solo.

Si lo que te piden es *"actualiza stele"*, el ritual es **otro**: ACTUALIZAR, en `.stele/SKILL.md`.
No hay archivo de versión que consultar — lo que manda es el **diff** entre el kit que ya tienes y el
nuevo. Por eso la copia nueva se trae **a un temporal, al lado**, y no encima: primero se lee el
diff, y solo después se sustituye el kit.

No improvises la estructura: la fuente de verdad de rituales es `.stele/SKILL.md`, y el *por qué* y
las fronteras están en `.stele/guide.md`. Léelos antes de escribir nada.

## Arquitectura (tres capas)

- **Núcleo** (`core/`) — roles + rituales + principios, agnósticos. Se define sobre **ids de rol
  estables**, no sobre nombres de archivo. Roles en `core/roles.md`; plantillas en `core/templates/`.
- **Módulos** (`modules/<nombre>/`) — paquetes de roles + disciplinas. Incluido: `software`
  (añade `specs`/`architecture`/`gotchas`/`effort` + convenciones + la regla del checkpoint antes
  del primer archivo de código). Un proyecto no-software no lo activa.
- **Config** (`stele.config.md`, en la raíz del proyecto destino) — **fuente única** que enlaza
  `rol → nombre`, activa módulos, fija toggles/presupuestos/wording/idioma, declara las **tres
  rutas** — `kit` (dónde vive el marco, default `.stele`), `base` (dónde viven tus docs, default
  `.`) y `loader` (el auto-arranque, default `CLAUDE.md`) — y la **persistencia** (`git` ·
  `ninguna` · `comando`: cómo se vuelve durable el trabajo al cerrar). De aquí se **generan** el
  auto-arranque y el mapa de documentación.

## Qué contiene esta carpeta

- **`SKILL.md`** — hoja operativa: rituales *bootstrap · abrir · checkpoint · cerrar · auditar ·
  contrastar · remitir · actualizar · config*, el mapa de documentación (cómo se genera) y la
  convención de tokens. Léelo primero.
- **`guide.md`** — el *por qué*: pilares, arquitectura de capas, roles y fronteras, presupuestos.
  Referencia; se lee una vez.
- **`core/`** — `roles.md` (roles del núcleo, fuente del mapa derivado) + `templates/` (plantillas
  por rol: `entry`, `charter`, `protocol`, `state`, `handover`, `index`, `session`, `audit`,
  `correspondence`, `letter`, `autostart`, `config`).
- **`modules/software/`** — `module.md` (manifiesto), `roles.md`, `conventions.md` y `templates/`
  (`specs`, `architecture`, `gotchas`, `effort`).
- **`buzon.md`** — correspondencia de stele hacia quien usa el marco. **Baja sola** con cada
  actualización (no hay servicio ni cuenta: el kit se copia, y las cartas viajan con él). Contiene
  preguntas que solo pueden responder proyectos reales. Se contesta con el ritual REMITIR, por el
  canal que prefieras — copiar y pegar basta.

Las plantillas se escriben **por rol** con tokens `{{rol}}`; bootstrap/`config` los resuelven a los
nombres del manifiesto (los docs instanciados quedan con nombres concretos y legibles).

## Instalar en un proyecto (vendorizado)

El marco es **markdown puro** (sin runtime): se instala **vendorizando** una copia del kit dentro
del proyecto, en la ruta `kit` (default `.stele/`). La copia es la fuente para el agente; para
actualizar se sustituye entera con el ritual **ACTUALIZAR** (que primero saca el diff y luego
reconcilia tu instancia) — por eso **tus docs (`base`) nunca pueden vivir dentro del kit**.

1. Trae el kit a `<proyecto>/.stele/` (elige uno):

   ```bash
   # opción a — degit (sin historia git, recomendado)
   npx degit emezav/stele .stele
   # opción b — clonar y copiar
   git clone --depth 1 git@github.com:emezav/stele.git /tmp/stele && mkdir -p .stele && cp -r /tmp/stele/. .stele/ && rm -rf .stele/.git
   ```

2. Pide al agente **"bootstrapea la stele"** (ritual BOOTSTRAP en `.stele/SKILL.md`): detecta
   greenfield vs adopción, elige `idioma`/`módulos` y las tres rutas (con defaults), te muestra el
   layout resuelto, escribe `stele.config.md` en la raíz, instancia las plantillas bajo `base`, y
   genera el loader de auto-arranque + el mapa-doc.
3. El **loader** (ruta `loader`, por defecto `CLAUDE.md`) es la activación automática: el agente lo
   carga al iniciar la sesión, hace `@`-import del set de arranque y saluda con 1-3 líneas (señal de
   que arrancó). Cámbialo si tu agente espera otro nombre (`AGENTS.md`, etc.).
4. (Opcional, Claude Code) para que `/stele` recuerde los rituales bajo demanda, vendoriza el kit
   directamente en `.claude/skills/stele` y pon `kit = .claude/skills/stele`: una sola copia, que se
   actualiza en un solo sitio. Si ya lo tienes en `.stele/`, `cp -r .stele .claude/skills/stele`
   también funciona, pero deja dos copias que hay que mantener sincronizadas a mano.

Para cambiar nombres, activar/desactivar módulos o mover cualquiera de las tres rutas después:
ritual **CONFIG** (no editar los derivados a mano).

**Layouts con nombre:** hay cuatro atajos para las combinaciones habituales de `kit` + `base` —
`default`, `agrupado`, `docs` y `skill`. Puedes pedir uno por su nombre ("bootstrapea con layout
agrupado"), y bootstrap te dice cuál resolvió antes de escribir nada. La tabla con los valores de
cada uno está en `SKILL.md` → "Layouts con nombre"; no son un parámetro que se guarde, solo una
forma corta de nombrar dos rutas.

> Detalle de rituales y plantillas: `SKILL.md`. Fundamentos, capas y fronteras: `guide.md`.
> El historial de diseño del marco vive en `git log`, no en el kit: todo lo que se vendoriza es lo
> que un agente necesita para trabajar.

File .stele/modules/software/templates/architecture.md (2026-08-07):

# {{architecture}} — <área/producto>

> Mapa de módulos y **patrones reutilizables** de este producto (normalmente un codebase). Objetivo:
> que ningún agente tenga que releer el fuente para redescubrir un patrón ya entendido. Se **lee** al
> inicio de cualquier sesión que toque esta área y se **actualiza** al cerrar si se descubre un patrón
> nuevo. Uno por producto (monorepo: uno por paquete relevante).
>
> Frontera: aquí va *cómo está organizado el producto* (estructura + patrones). Las *trampas
> puntuales* van en `{{gotchas}}`; las *decisiones de producto* en `{{specs}}`.

## Stack
ADAPTAR: lenguaje, framework, librerías clave, cómo se construye/corre.

## Estructura de módulos
ADAPTAR: directorios/paquetes y su responsabilidad, en una línea cada uno.

## Patrones reutilizables ⭐
ADAPTAR: los patrones que se repiten y conviene conocer antes de escribir. Por patrón:
- **<Nombre del patrón>** — qué resuelve, dónde está la implementación de referencia
  (`ruta/archivo.ext`), y cómo usarlo. (p. ej. capa de acceso a datos, manejo de auth,
  componente de tabla estándar, proxy/BFF, manejo de errores.)

## Flujos clave
ADAPTAR: 1-3 flujos de punta a punta que un agente nuevo debe entender (p. ej. "petición →
proxy → API → DB", "evento en tiempo real", "build/deploy").

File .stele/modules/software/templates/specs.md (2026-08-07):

# {{specs}} — Qué hace el producto (specs, contratos, decisiones por feature)

> **Fuente de verdad del producto**: specs, contratos de API, modelo de datos, decisiones por
> feature, contexto de negocio detallado. Es lo que perdura y comparten todos los agentes y
> sesiones. Frontera: los *principios y apuestas grandes transversales* van en `{{charter}}`;
> los *patrones de código* en `{{architecture}}`; las *trampas de código* en `{{gotchas}}`.
>
> **Estructura:** una sección `§` por decisión o feature, **autocontenida**. Este archivo se lee con
> `grep` y por rango, nunca entero: lo que importa es que cada sección sea corta por sí misma, no el
> tamaño del total. **Umbral de extracción: ~50 líneas** — por encima, la decisión se mueve a un
> archivo de tema (`{{specs_dir}}<TEMA>.md`) y aquí queda un resumen de 2-3 líneas + link. Un tema
> que supera ~600-800 líneas se divide en sub-temas.

## Cómo usar este archivo

- **Antes de implementar**, `grep -n` la sección relevante y lee solo esa parte (no el archivo completo).
- **Toda decisión** de producto/arquitectura/integración/negocio que deba perdurar se documenta
  aquí *en el momento en que se toma* — si no está aquí, es invisible para otros agentes y sesiones.

## § Índice de decisiones

ADAPTAR: una sección por decisión/feature, autocontenida y por debajo de ~50 líneas; con link al
tema cuando la haya superado.

### §1 — <Área / feature>

- **<Decisión / contrato / regla>** — el qué, el porqué y lo que se descartó. Si esta sección pasa
  de ~50 líneas, se extrae: `{{specs_dir}}<TEMA>.md`.

## Modelo de datos

ADAPTAR: entidades clave y relaciones (o link al tema). Identificadores canónicos y qué NO confundir.

## Contratos de API / integración

ADAPTAR: endpoints/convenciones estables (o link al tema por recurso).

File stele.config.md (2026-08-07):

# stele.config — Configuración del marco

> Fuente única de la configuración de ESTE proyecto. La editas a mano o con el ritual `config`
> (`.stele/SKILL.md`). El **auto-arranque** y el **mapa de documentación** se GENERAN de aquí —
> no los edites por separado. Todo lo accionable va en **tablas**; la prosa solo explica.
>
> **Contrato de parseo:** los headers `##` son secciones canónicas y fijas, en este orden:
> `Meta` · `Rutas` · `Nombres` · `Features` · `Presupuestos` · `Wording de rituales`. Se
> referencian por posición, no por su texto. En cada tabla, col1 = clave, col2 = valor; columnas
> y filas extra se ignoran. `—` en un nombre = rol desactivado. Fila ausente = default del
> rol/feature (ver `.stele/core/roles.md` y `.stele/modules/<mód>/`). Al aplicar un cambio,
> `config` reescribe la tabla afectada **completa** y regenera los derivados.

## Meta

| Parámetro | Valor |
| --- | --- |
| idioma | es |
| módulos | software |
| persistencia | git |
| persistencia_cmd | — |
| kit_origen | `https://github.com/emezav/stele` |
| remitente | — |
| remitente_publico | — |

## Rutas

| Ruta | Valor | Qué es |
| --- | --- | --- |
| kit | .stele | El marco vendorizado (`SKILL.md`, `guide.md`, `core/`, `modules/`). |
| base | bitacora | Raíz de los docs instanciados (layout `agrupado`). |
| loader | CLAUDE.md | Loader de auto-arranque, siempre en la raíz. GENERADO. |

## Nombres (rol → archivo)

| Rol | Archivo | Origen |
| --- | --- | --- |
| entry | AGENTS.md | núcleo |
| charter | design.md | núcleo |
| protocol | protocol.md | núcleo |
| state | latest.md | núcleo |
| handover | handover.md | núcleo |
| index | index.md | núcleo |
| history_dir | history/ | núcleo |
| session | sesion-{NNN}-{YYYY-MM-DD}.md | núcleo |
| audit | audit.md | núcleo |
| correspondence | cartas.md | núcleo |
| letter | carta-{NNN}-{YYYY-MM-DD}.md | núcleo |
| correspondence_dir | correspondencia/ | núcleo |
| artifacts_dir | artefactos/ | núcleo |
| gotchas | memory.md | software |
| specs | requirements.md | software |
| specs_dir | temas/ | software |
| architecture | architecture.md | software |
| effort | esfuerzo.md | software |

## Features (toggles)

| Feature | Valor |
| --- | --- |
| effort_log | on |
| effort_unit | horas-ingeniero |
| session_greeting | on |
| audit_log | on |
| audit_every_n_sessions | 10 |
| correspondence_log | on |

## Presupuestos

| Doc (rol) | Máx. líneas |
| --- | --- |
| state | 100 |
| handover | 50 |

## Wording de rituales

| Ritual | Parámetro | Texto |
| --- | --- | --- |
| checkpoint | trigger | antes de la primera edición de código |
| abrir | saludo | 1-3 líneas: última sesión + estado handover + próximo paso |

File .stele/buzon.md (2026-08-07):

# buzon.md — Correspondencia de stele hacia quien usa el marco

> **Qué es.** El buzón de salida del kit. Como ACTUALIZAR se trae el árbol entero, **estas cartas
> bajan solas** con cada actualización: no hay servicio, ni red, ni cuenta que crear. Tu agente lo lee
> al actualizar (tabla de zonas de impacto, `SKILL.md`) y te dice si hay algo para ti.
>
> **Qué hacer con una carta.** Si te interesa, contéstala con el ritual **REMITIR** (`SKILL.md`) y
> mándala por donde quieras — pegarla en la sesión de tu agente, un correo, un issue. Copiar y pegar
> basta; no hace falta saber git ni tener cuenta en ninguna parte. Si la contestas o te mueve a hacer
> algo, **archiva tu copia**: este buzón se cura, y lo de aquí desaparece.
>
> **Regla de curación (importante).** Este archivo es **carga pública y permanente**: viaja a cada
> copia del kit. Por eso se poda —una pregunta contestada se retira— y el rastro queda en `git log`.
> Mismo criterio que el resto del marco: lo histórico vive en la historia, no en el kit.
>
> **Sobre nombres.** Aquí no se nombra a nadie sin su permiso: un proyecto aparece por el `remitente`
> con el que firmó, o en anónimo. Y las cartas hablan de **ideas**, nunca de quien las tuvo.
>
> **El tachado rige también hacia aquí.** Lo que se publica en este buzón suele nacer de un informe que
> llegó **en privado**, y esos informes vienen llenos de tripas de quien los mandó: rutas internas,
> nombres de máquinas y servicios, datos de terceros. Contestar en público sin releer con esa lente
> **filtra lo que se contó en confianza**, y el seudónimo no protege de eso. Se tacha antes de bajar,
> igual que antes de subir.

---

## Carta 1 — Aviso: dos archivos del kit cambiaron de nombre

**De:** stele · **Para:** todo el que ya tuviera el kit · **Fecha:** 2026-08-07

**El caso.** El kit pasó a la regla *"minúscula por defecto; MAYÚSCULA solo donde la impone algo
externo"*. Sobreviven en mayúscula `README.md`, `LICENSE`, `CLAUDE.md`, `AGENTS.md` y `SKILL.md` — este
último **no** por GitHub sino por el layout `skill`, donde Claude Code busca ese nombre exacto.

Cambiaron dos: **`GUIDE.md` -> `guide.md`** y **`BUZON.md` -> `buzon.md`**.

**Lo que te afecta, y no lo cubre la tabla de zonas.** Si algún doc **tuyo** enlaza al kit por el
nombre viejo, ahora tienes una referencia colgada. La tabla dice que `guide.md` "se lee, no se migra",
lo cual es cierto para su contenido y **no dice nada de tus enlaces hacia él**. Compruébalo:

```bash
# acotado a TUS docs: sustituye <base> por tu ruta base (`.`, `docs`, `bitacora`…)
grep -rn "GUIDE\.md\|BUZON\.md" <base> --include="*.md"
```

**Acota el comando a tu `base` en vez de barrer desde la raíz**, y no es un detalle: el kit vive en un
directorio **oculto**, y las herramientas no coinciden en qué hacer con eso — `ripgrep` lo salta por
defecto, `grep -r` de GNU entra. Barriendo desde la raíz con GNU te salen las referencias **internas
del kit**, que están perfectamente bien, y parecen enlaces rotos.

Lo que salga dentro de tu `base` es tuyo y hay que corregirlo a mano. Y si estás en Windows, ojo: el
sistema de archivos no distingue mayúsculas, así que el enlace viejo **te sigue funcionando ahí** y se
romperá en el primer clon en Linux. Arréglalo igual.

**Qué NO demuestra este caso.** No sabemos cuántos adoptantes enlazan al kit por nombre; puede que
ninguno. El aviso cuesta menos que el silencio.

## Carta 2 — Qué se rechazó de los reportes de campo, y por qué

**De:** stele · **Para:** quien vaya a reportar algo · **Fecha:** 2026-08-07

Las **reglas** que salieron de los reportes ya están en el kit; lo que el kit no lleva son los
**descartes**, y son lo que más viaje ahorra. Tres, sin nombrar a nadie:

- **No se creó un módulo nuevo para los detectores de red.** La propuesta era razonable —puertos y
  servicios no son "software" en general, sino proyectos que operan servicios— pero aquí **un módulo
  es un paquete de roles**, y ese aporte no traía ninguno. Va condicionado dentro de `software`.
- **No se suben los presupuestos porque alguien los exceda.** Un tope que sube cada vez se convierte
  en decoración. Se decide: se poda con criterio, o se sube con `config` **después** de podar. Y un
  presupuesto no distingue *"el proyecto creció"* de *"el doc derivó de género"* — la pregunta *"¿qué
  sobra?"* es lo único que las separa.
- **No se finge privacidad en un buzón.** El kit se copia entero, así que no hay destinatarios ni
  entrega selectiva: un archivo con el nombre de alguien sería *algo que parece protegido sin
  estarlo*. Lo privado va por otro canal, que es el modo por defecto de todos modos.

**Y la regla que gobierna esto:** el **diagnóstico viaja, el remedio no**. Cuatro de cuatro reportes
llegaron con el diagnóstico correcto y el remedio equivocado o incompleto — no por torpeza, sino
porque quien reporta tiene el **caso** y el proyecto tiene el **contexto de diseño**. Escribe el caso;
la propuesta es la parte menos valiosa de tu carta y no hace falta traerla.

## Carta 3 — ¿Tu loader tenía contenido propio antes de adoptar stele?

**De:** stele · **Para:** cualquiera que haya adoptado el marco · **Fecha:** 2026-08-07

**El caso.** El marco tiene una regla dura, el *invariante 6*: si el archivo de auto-arranque
(`CLAUDE.md`, `AGENTS.md`, el que uses) **ya existía**, se **modifica** y no se recrea — el bloque del
marco va entre las marcas `STELE:INICIO` / `STELE:FIN` y **todo lo que quede fuera se conserva
íntegro**. La regla nació de un fallo real: en el primer bootstrap fuera del repo original, el ritual
tomó un `CLAUDE.md` escrito a mano por el nombre de un derivado y lo sobrescribió entero. Se perdió el
contenido.

**Lo que no podemos comprobar.** La mitad de esa regla sigue **sin probarse en campo**. Un proyecto
que ya actualizó nos confirmó que el bloque se porta bien, pero **no tenía nada fuera de las marcas**,
así que su caso no dice nada sobre la conservación de lo externo. Aquí tampoco podemos probarlo: este
repo genera su propio loader.

**Lo que preguntamos, y son dos preguntas distintas.** Si tu proyecto tenía un `CLAUDE.md` o un
`AGENTS.md` **escrito a mano antes** de adoptar el marco:

1. ¿Quedó texto tuyo **FUERA** de las marcas `STELE:INICIO`/`STELE:FIN`? Si es así: ¿sigue ahí
   íntegro tras el bootstrap y las actualizaciones? Y si se perdió algo, ¿qué ritual lo tocó?
2. ¿Tu texto propio acabó **DENTRO** de las marcas — porque al insertar el bloque se rodeó lo que ya
   había en vez de añadirlo aparte?

**La segunda es la que más nos importa, y la aprendimos tarde.** Al preguntar solo por la primera, un
proyecto nos contestó *"fuera de las marcas no tengo nada"* y dimos por hecho que su caso no servía.
No era así: su contenido preexistía, solo que **encerrado dentro**. Y ahí el invariante 6 no protege
nada, porque no hay nada fuera que conservar — todo lo propio está en la zona que el marco se autoriza
a reescribir. Es la situación más peligrosa de las tres y desde fuera se ve igual que un loader
generado de cero.

Si estás en ese caso: **marca tu bloque como `STELE:INICIO RICO` ahora**, antes de la próxima
actualización. Ahí la marca no es una comodidad — es lo único que se interpone.

**Qué NO nos sirve.** Si tu loader lo generó el bootstrap desde cero y nunca escribiste nada a mano,
tu caso no responde a ninguna de las dos. Hace falta un archivo que **preexistía**.

**Por qué te lo pedimos a ti.** Es una pregunta que el marco no puede contestarse solo: solo la
responde alguien que llegó con documentación propia. Y de esa respuesta depende una regla que hoy
protege datos que no podemos ver.

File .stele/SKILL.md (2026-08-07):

---
name: stele
description: >
  Marco modular y configurable de documentación y continuidad para trabajar en un proyecto a
  través de muchas sesiones sin perder contexto y con coste de tokens acotado. Sirve para software
  y para trabajo no-software (materiales, planeación, investigación). Úsalo al INICIAR una sesión
  (ponerse al día), al CERRAR (registro durable), antes de un cambio interrumpible (checkpoint),
  para AUDITAR la documentación (verificar que lo escrito sigue siendo cierto), para INICIALIZAR el
  marco en un proyecto (bootstrap), para ACTUALIZARLO a una versión nueva del kit (actualizar), o
  para ADAPTARLO (config: nombres, módulos, parámetros). Núcleo agnóstico + módulos (software) +
  config (stele.config.md).
---

# stele — rituales de sesión

> Hoja operativa. El *por qué* y las fronteras están en `guide.md` (leer una vez). Plantillas en
> `core/templates/` y `modules/<mód>/templates/`. Roles en `core/roles.md` y `modules/<mód>/roles.md`.
> Regla madre: **un hogar por dato; el estado se sobrescribe; el historial es append-only; lee poco
> al arrancar.** Los nombres de archivo salen del manifiesto `stele.config.md`.

## Mapa de documentación (GENERADO — consúltalo antes de leer/escribir)

El mapa "necesito X → tal archivo" **no se escribe a mano**: se genera en el doc `entry` desde los
`triggers` de los roles activos + el binding de la config. Regla de generación:

- **Roles activos** = roles del núcleo (`core/roles.md`) + roles de los módulos activos, menos los
  que tengan nombre `—` en la config.
- **Lista de arranque** = roles `startup: obligatorio`, ordenados por `order`, nombre resuelto
  (`{base}/[{history_dir}/]{nombre}`). El resto va a la nota "bajo demanda con grep".
- **Tabla de enrutamiento** = una fila `trigger → nombre` por cada rol activo.

Se regenera en `config` y al activar/desactivar módulos o renombrar. **Regla de oro anti-tokens:**
no leas un archivo entero "por si acaso"; usa el mapa y `grep -n` + lectura por rango.

## El punto inicial significa "maquinaria", y conviene decirlo

El kit vive en un directorio oculto (`.stele`, `.claude/skills/stele`) y tus documentos no. **Eso no
es casualidad: el punto marca lo que el marco se autoriza a sustituir entero.** Lo que empieza por
punto es reemplazable y no se edita a mano; lo que no, es tuyo y el marco no lo toca jamás.

Estaba en vigor desde el principio y nunca se había escrito, que es como una convención deja de
comunicar.

**Con un límite que hay que reconocer:** la convención del punto **es legible exactamente para quien
no la necesita**. Quien programa ya sabe que lo oculto es herramienta; quien no, no tiene por qué
saberlo — y es justo el público al que se le recomienda `agrupado`. Por eso declararla **no sustituye**
a que las dos carpetas se llamen distinto: lo acompaña.

**Consecuencia práctica que sorprende:** un directorio oculto **no lo tratan igual todas las
herramientas**. `ripgrep` y muchos buscadores lo saltan por defecto; `grep -r` de GNU entra. Así que
un mismo comando de barrido da resultados distintos según qué tenga instalado quien lo corre — y por
eso **todo comando que publiques debe acotar dónde busca** en vez de fiarse del default.

## Precedencia frente a los defaults del harness

**Dónde vive lo que produces en este proyecto lo decide el marco, no la herramienta que te ejecuta.**
Muchos harnesses inyectan un área de trabajo propia —scratchpad, memoria del agente, temporal de
subagente— y la marcan como prioritaria. Es un default razonable *para la herramienta*, y es el
equivocado *para el proyecto*: lo que se escribe ahí no lo ve el siguiente agente, no lo ve el humano,
y no queda en el registro. Ante conflicto, manda el mapa de documentación y el hogar de artefactos.

**El límite, y hay que respetarlo:** esta precedencia cubre **el destino de los archivos**. No alcanza
a las reglas de seguridad del harness, ni a cómo usa sus herramientas, ni a sus permisos. Una regla
que reclama más de lo que le toca se ignora entera, y con razón.

Esto no es una regla de estilo: es la que evita que el marco pierda en silencio. Ha hecho falta
escribirla dos veces por el mismo motivo — un default externo vació una regla del marco que nunca dijo
quién manda, y las dos veces lo descubrió una persona leyendo, no el mecanismo.

## Convención de tokens en plantillas

Las plantillas se escriben por **rol** y usan tokens que bootstrap/`config` resuelven a nombres:
`{{rol}}` → nombre del rol (p. ej. `{{state}}`→`latest.md`); `{{history_dir}}`, `{{specs_dir}}`,
`{{artifacts_dir}}` y `{{correspondence_dir}}` → **rutas** de los roles contenedores;
`{{budget:rol}}` → tope de líneas; `{{effort_unit}}` y
`{{checkpoint_trigger}}` → valores de Features/Wording; `{{kit}}` y `{{loader}}` → rutas
(sección Rutas). Los toggles como `session_greeting` **se consultan, no se interpolan**: no hay
token para ellos.
Los bloques marcados `<!-- GENERADO -->` los produce el marco, no se editan a mano.

**Toda ruta interpolada es relativa a la raíz del proyecto**, nunca al doc que la contiene: los
agentes operan con el CWD en la raíz y es lo que hace `grep`, así que el valor no depende de dónde
quedó cada archivo. De ahí dos reglas de composición:

- `{{kit}}` se escribe **sin `/` final** y se usa como `{{kit}}/SKILL.md`. **Con `kit = .` el prefijo
  colapsa**: `{{kit}}/SKILL.md` → `SKILL.md`, no `./SKILL.md`.
- Los **contenedores** (`{{history_dir}}`, `{{specs_dir}}`, `{{artifacts_dir}}`, `{{correspondence_dir}}`) resuelven **con `base` delante y con `/`
  final**, así que se concatenan directos, sin barra intermedia: `{{history_dir}}{{index}}` →
  `stele/history/index.md` con `base = stele`, y `history/index.md` con `base = .` (el prefijo
  colapsa igual que en `{{kit}}`). En el manifiesto el valor configurado es solo el nombre de la
  carpeta (`history/`); es el token el que le antepone `base` al resolverse.

Esto importa sobre todo en lo **ejecutable**. Un `printf '…' >> {{history_dir}}{{index}}` mal
compuesto no da error: crea el archivo que falta y deja el de verdad sin la fila.

**Dos clases de ruta, y no se resuelven igual** — confundirlas es lo que rompe enlaces al mover
`base`:

- **Ruta de comando** (`printf >> …`, `grep`, `git log --`): relativa a la **raíz del proyecto**,
  porque los agentes operan con el CWD ahí. Es la que producen los tokens.
- **Enlace Markdown clicable** (`[index.md](./index.md)`): relativo al **archivo que lo contiene**,
  porque así lo resuelve cualquier visor. Sobrevive a un cambio de `base` solo si su destino se mueve
  en el mismo bloque — que es el caso dentro de `{{history_dir}}`, y por eso el historial se mueve
  entero y no se reescribe. Un enlace que apunte **fuera** del bloque movido sí se rompe: revísalos
  al migrar.

## Las tres rutas: `kit` · `base` · `loader`

| Ruta | Default | Qué contiene | Quién la escribe |
| --- | --- | --- | --- |
| `kit` | `.stele` | El marco vendorizado. Maquinaria **reemplazable**. | Ritual ACTUALIZAR |
| `base` | `.` | Los docs instanciados (roles). Contenido **del proyecto**. | El agente, cada sesión |
| `loader` | `CLAUDE.md` | Auto-arranque, siempre en la raíz. GENERADO **por bloque**. | `bootstrap`/`config` |

**Invariantes** (validar en `bootstrap` y en `config`, antes de escribir):

1. `base` **nunca** dentro de `kit`: actualizar reemplaza el directorio del kit entero, y se llevaría
   los docs por delante. Violación = abortar. **Excepción: modo auto-hospedado** (`kit = .`), cuando
   el proyecto **es** el marco — el repo del kit. Ahí el kit no se vendoriza: se desarrolla en sitio
   y nunca se borra, así que la razón del invariante no aplica y `base` es por fuerza un
   subdirectorio suyo. En ese modo `base` debe ser un subdirectorio propio, nunca `.` (ver 2).
2. `kit` == `base` = abortar (misma razón, caso degenerado).
3. `kit` dentro de `base` (p. ej. `base = stele`, `kit = stele/.stele`) es legal pero **se avisa**:
   los `grep` del ritual de apertura empiezan a encontrar plantillas del marco como si fueran docs
   del proyecto.
4. El `loader` vive en la raíz y no puede colisionar con el nombre de un rol resuelto bajo `base`
   (con `base = .` y `loader = AGENTS.md` chocaría con `entry`). Colisión = abortar.
5. `stele.config.md` y el `loader` son las **dos anclas fijas de la raíz**: no siguen a `base`.
6. **Si el archivo del `loader` ya existe, se MODIFICA — nunca se crea de cero.** Su contenido es del
   usuario: se conserva íntegro y el bloque del marco se **inserta** entre las marcas
   `STELE:INICIO` / `STELE:FIN`. Solo ese bloque se reescribe después. Sobrescribir el archivo entero
   destruyó el `CLAUDE.md` de un proyecto real. Vale igual en `bootstrap` y en `config`.
   **Y si la marca de apertura dice `RICO`, ese bloque tampoco se reescribe entero:** el proyecto lo
   enriqueció con reglas propias, así que se porta el delta a mano. Vale en `config` igual que en
   `actualizar` — los dos rituales tocan ese bloque.

**El loader es derivado en parte, no desechable.** Lo generado es el bloque; el **archivo** puede ser
compartido con contenido del proyecto — muchos equipos ya tenían un `CLAUDE.md` o un `AGENTS.md`
escrito a mano antes de adoptar el marco. Se le aplica la misma regla de adopción que a cualquier doc
de rol: mapear y añadir, jamás reemplazar.

### Layouts con nombre (vocabulario, no parámetro)

Cuatro combinaciones de `kit` + `base` cubren casi todos los proyectos. Son **atajos de
conversación**: se resuelven a las tres rutas y **nunca se guardan en el manifiesto**. El layout es
derivable de la sección Rutas; guardarlo crearía un segundo hogar del mismo dato, que se
desincroniza en cuanto alguien mueva una ruta.

| Layout | `kit` | `base` | Para quién |
| --- | --- | --- | --- |
| `default` | `.stele` | `.` | Docs en la raíz, marco invisible |
| `agrupado` | `.stele` | `bitacora` | Tus docs juntos en una carpeta visible |
| `docs` | `.stele` | `docs` | Proyecto con carpeta de docs ya establecida |
| `skill` | `.claude/skills/stele` | `bitacora` | Claude Code: una sola copia del kit, además usable como `/stele` |

Cualquier otra combinación es legal y se nombra `personalizado` (incluido el modo auto-hospedado,
`kit = .`). El `loader` **no** forma parte del layout: depende del agente, no del proyecto.

**Por qué `base` no se llama como el marco.** El nombre obvio para `agrupado` sería `stele/`, y estuvo
así hasta que un proyecto lo señaló al agrupar: **`.stele/` y `stele/` se diferencian en un punto**, y
son cosas opuestas — una es maquinaria que se sustituye entera al actualizar, la otra son **tus
documentos**, los que editas cada sesión.

Y el fallo **no es simétrico**: escribir en tus docs creyendo que es el kit no rompe nada; **escribir
dentro del kit creyendo que son tus docs hace que el cambio desaparezca en la próxima actualización,
sin error y sin aviso**. Un nombre distinto elimina la confusión de raíz, sin depender de que nadie
entienda la convención del punto.

**Aviso antes de elegir `agrupado` o `docs`:** si el `entry` se llama `AGENTS.md`, hay agentes
(Codex y otros) que lo **auto-cargan desde la raíz** igual que Claude Code carga `CLAUDE.md`. Sacarlo
de la raíz con `base != .` no rompe nada visible —el loader sigue funcionando— pero esos agentes
dejan de leer el `entry` por su cuenta. Falla en silencio. Si trabajas con alguno de ellos, o
`base = .`, o renombra el `entry` a algo que no sea `AGENTS.md`.

Se usan de tres maneras:

- **En el eco**, siempre: nombrar el layout resuelto dice más, y más rápido, que tres rutas sueltas.
  Un usuario que pidió "agrupado" detecta `layout -> default` al instante.
- **Como menú**, solo cuando el ritual ya iba a preguntar (BOOTSTRAP paso 1, "ante duda real"). No
  convierte el bootstrap en un cuestionario: sin ambigüedad se aplican los defaults sin preguntar.
- **Como entrada**: "bootstrapea con layout agrupado" o "pásame a layout docs" son peticiones
  válidas; se traducen a valores de ruta y se previsualizan como tales.

## Cómo se le habla al usuario (registro llano)

El marco tiene **dos vocabularios**, y solo uno es contrato:

- **Vocabulario de datos** — ids de rol, claves y headers `##` del manifiesto, estados
  (`EN_PROGRESO`), nombres de archivo. Se **parsean**: no se traducen ni se adornan, ni en los docs
  ni en los comandos. Es la misma razón por la que `idioma` no traduce los ids.
- **Registro de habla** — lo que **dices**: saludo, ecos, informes, preguntas, resúmenes. No lo
  consume ninguna máquina, así que aquí no hay contrato que romper.

**Regla: al usuario se le habla en llano, y se nombra el archivo.** No *"el handover está en
`EN_PROGRESO`"*, sino *"quedó trabajo a medias, con su alcance anotado (`handover.md`)"*. El nombre
entre paréntesis va **siempre**: es lo que le permite ir a mirarlo, y lo que hace que hablar claro no
le quite precisión a un usuario técnico. Por eso la regla no necesita un parámetro que la active.

**Suavizar no es diluir.** Se traduce el **nombre** del concepto; **nunca se esconde el hecho**. Si
hay trabajo a medias, un doc que se contradice o una migración a medio aplicar, se dice — en llano y
sin rodeos. Un resumen tranquilizador es peor que la jerga.

| Concepto del marco | Cómo se dice |
| --- | --- |
| `handover` en `EN_PROGRESO` | quedó trabajo a medias, con su alcance anotado |
| checkpoint | dejar guardado dónde vas, antes de algo que se puede interrumpir |
| bootstrap | preparar el proyecto la primera vez |
| `kit` / `base` / `loader` | el marco / tus documentos / el archivo que arranca al agente |
| layout (`agrupado`, `docs`…) | dónde va cada cosa: todo el marco junto, o los docs en `docs/`… |
| manifiesto | el archivo de configuración |
| rol / token / derivado | (no se nombran: se dice el archivo, o "se regenera solo") |
| instancia | tus documentos, los que ya existen en el proyecto |
| drift | documentación que se quedó desactualizada |
| clase 7 (AUDITAR) | un dato que se quedó en el registro de una sesión y nunca llegó a su sitio |
| append-only | solo se añade; no se reescribe lo anterior |
| vendorizar / actualizar el kit | traer al proyecto una copia del marco / traer la versión nueva |
| presupuesto de un doc | el tamaño máximo que debería tener |

Esto **no cambia nada de lo que se escribe**: los docs, el manifiesto y los mensajes de commit siguen
con el vocabulario del marco. Un documento lo lee el siguiente agente; el habla la lee quien está
delante ahora.

**El habla va en el `idioma` del proyecto, con su ortografía natural.** Con `idioma = es` se habla
con acentos y con `ñ`. Una regla de "solo ASCII" —del proyecto o de la configuración del agente—
gobierna **lo que se escribe a un archivo**: ids, claves, nombres, código y cualquier texto que otra
herramienta vaya a parsear. El habla no es eso: es prosa dirigida a una persona, y nada la parsea. El
eje no es qué idioma, sino **a dónde va**. Un saludo sin acentos se lee como un fallo de codificación
en la primera línea que ve el usuario — el sitio más caro para parecer roto.

## Ritual: ABRIR sesión (ponerse al día, barato)

Lee, en orden, SOLO la **lista de arranque** del proyecto (generada; con defaults del módulo software):
1. `entry` · 2. `gotchas` · 3. `state` · 4. `handover` — **si su Estado ≠ `SIN_TRABAJO_ACTIVO`**,
respétalo antes de editar. Bajo demanda (grep): `charter` (1ª vez / orientación), `protocol`,
`specs`, `architecture`, `index`/`session`.

**Confirma el arranque (visible):** un agente **no puede hablar antes de que el usuario escriba**,
así que la confirmación va **al frente de tu PRIMERA respuesta** — 1-3 líneas: última sesión
(N + título), si quedó trabajo a medias, próximo paso propuesto. En llano, nombrando los archivos
(ver "Cómo se le habla al usuario"). Sin esto, el arranque silencioso es
indistinguible de uno que no corrió. (Se omite si `session_greeting = off`.)

## Regla dura: checkpoint antes de un cambio interrumpible

Deja `handover` en `EN_PROGRESO` con objetivo + alcance + verificación prevista (plantilla
`core/templates/handover.md`) **{{checkpoint_trigger}}**. No es opcional ni depende del tamaño: una
sesión puede cortarse en cualquier momento y el checkpoint (~20 líneas) siempre cuesta menos que
reconstruir el contexto desde el diff. (El módulo software especializa el trigger a "antes del primer
archivo de código".)

**Exención:** cambios que SOLO tocan el **contenido** de la documentación. **No exime una migración
estructural** — mover, renombrar o reestructurar docs, es decir los rituales CONFIG y ACTUALIZAR —
aunque no toque una línea de código: si se corta a la mitad, media instancia está en un sitio, el
manifiesto ya declara otro y los comandos de cierre apuntan a donde no hay nada.

**Y aquí también van las trampas de ESTE salto**, no solo el objetivo y el alcance: lo que sabes que
puede salir mal en lo que estás a punto de hacer. No es adorno, es el sitio donde una advertencia
llega a tiempo.

La evidencia de campo tiene los dos lados, que es raro y por eso vale. Un proyecto anotó en su
checkpoint que una sustitución textual podía alcanzar al kit, hizo el cambio y **lo esquivó** — y
reconoce que sin ese aviso probablemente habría caído, porque los dos cambios equivalentes que había
hecho ese mismo día fueron ingenuos. Aquí, en cambio, la trampa equivalente estaba en `gotchas` —que
se lee al abrir cada sesión— y **no impidió el fallo que describía**, cometido una sesión después de
escribirla y encontrado cinco sesiones más tarde por una auditoría.

**Lo que decide no es solo que esté escrita: es la distancia al momento de uso.** Con un matiz que el
propio corresponsal aportó y que rebaja la conclusión — **su trampa estaba también en `gotchas`**, no
solo en el checkpoint. Así que la comparación limpia no es *"doc de arranque contra checkpoint"* sino
**"doc de arranque solo" contra "doc de arranque más checkpoint"**, y lo que muestra es que
**añadirlo funciona**, no que el doc de arranque sobre. Escríbela en los dos sitios si hace falta: el
de arranque te informa, el del salto te detiene.

## Ritual: CERRAR sesión (dejar registro durable)

1. **`session`** (nuevo): qué se hizo, decisiones, archivos, verificación, notas para retomar, y
   `## Esfuerzo equivalente` (si `effort_log`). `NNN` con padding a 3 dígitos.
2. **`index`**: una fila con append de Bash — `printf '| N | … |\n' >> {history_dir}{index}`.
3. **`effort`** (si `effort_log`): una fila con `printf >>`.
4. **`state`**: reescríbelo COMPLETO con `Write` según su plantilla (nunca prepend). Si `audit_log`
   está activo y desde la última fila de `audit` han pasado más de `audit_every_n_sessions`
   sesiones, anota **"auditoría vencida (última: sesión X)"** en *Pendientes operativos*. Es una
   comparación de dos números, no una verificación: cerrar no audita.
5. **Decisiones que perduran** → su hogar (mapa): producto/feature → `specs`; principio/decisión
   grande → `charter`; patrón de código → `architecture`; gotcha → `gotchas`. Nunca solo en historial.
6. **`handover`**: si cerró completo → `SIN_TRABAJO_ACTIVO` **apuntando a la sesión que cierras
   ahora**. Si quedó salto → `EN_PROGRESO`.
7. **Artefactos** (si la sesión produjo alguno en `{artifacts_dir}sesion-{NNN}/`): **nómbralos en el
   `session`** y marca cuáles **sostienen un cambio irreversible** — el script que movió los archivos,
   el que reescribió en lote. Esos son evidencia y no se podan; el resto es desecho y lo borra el
   usuario cuando quiera. **Tú no borras nada**: limpiar por tu cuenta destruye justo lo que hace
   auditable la sesión. Si no hubo artefactos, no se dice nada — no hay sección que rellenar.
8. **Persistir el cierre** según `persistencia` (manifiesto → Meta). El cierre se escribe primero
   (pasos 1-7) y se persiste **una sola vez**, al final.

**No registres un estado que no puedas observar.** Antes de escribir un hecho en un doc, pregúntate si
puedes comprobarlo desde donde estás. Lo que ocurre fuera de tu alcance —que una carta se entregó, que
un comando llegó a su destino, que alguien leyó algo— **no lo sabes: lo supones**, y una suposición en
un registro es peor que una ausencia, porque se lee como hecho y nadie vuelve a comprobarla. Cuando el
estado importe y no puedas observarlo, **regístralo por lo que sí sabes** —*redactada* en vez de
*enviada*— y deja que lo mueva quien sí puede verlo.

**Antes de persistir, comprueba lo que acabas de escribir contra las convenciones de texto de tu
proyecto** (si las tiene: solo-ASCII, terminología, lo que sea). **El marco no impone ninguna** —este
mismo kit está escrito en prosa acentuada a propósito—: el paso se parametriza con **las tuyas**, y si
tu proyecto no tiene convenciones de texto, no hay nada que comprobar. Lo aclaramos porque un lector
cuidadoso, con el kit delante, entendió lo contrario. No es una formalidad, y hay dos sitios
donde se escapa siempre: **las filas append-only** y **el mensaje de commit**. Son los dos únicos
momentos del cierre en que se redacta **prosa narrativa hacia un archivo**, con el mismo impulso con el
que se le habla al usuario — y ahí el registro equivocado se cuela sin que nadie lo note, porque el
resto de lo que se escribe son identificadores y rutas, donde el error salta solo. Compruébalo con un
comando, no releyendo: es lo que hace la diferencia entre una regla escrita y una regla aplicada.

**`persistencia = git`** — los archivos de cierre van en el **mismo commit** que el trabajo de la
sesión, no en uno aparte. Dile al usuario el `git push` exacto (o hazlo si lo autoriza). Reglas,
porque **un commit no puede contener su propio hash**:

- **No anotes el hash del commit que lleva el cierre.** Es información derivable, y por eso no se
  guarda: `git log --diff-filter=A -- {history_dir}{session}` devuelve el commit exacto de esa
  sesión. Guardar lo que se puede derivar es duplicar un hogar.
- **`--amend` solo mientras el commit sea privado y nadie lo cite.** El amend **cambia el hash**, así
  que un hash ya anotado queda apuntando a un commit inexistente, y falla en silencio. Dos
  condiciones, ambas comprobables antes de tocar nada: (a) **no se ha pusheado** y (b) **ningún doc
  anota su hash**. Si se cumplen —el caso típico es arreglar el mensaje del commit que acabas de
  hacer— el amend es seguro y no hay que dar rodeos. Si no se cumplen, no lo es: en particular,
  **nunca lo uses para plegar los docs de cierre dentro de un commit de trabajo cuyo hash ya
  anotaste**, que es el caso que originó la regla.
- Los hashes de commits **anteriores** de la sesión sí se anotan: existen y son estables.
- Si el trabajo ya se pusheó a mitad de sesión, el cierre va en un commit posterior. Es inevitable
  y está bien — ahí sí puede anotar el hash del trabajo. Que sea una decisión, no un accidente.

**`persistencia = ninguna`** — no hay VCS: los archivos en disco **son** el registro. Verifica que
todo quedó escrito y dile al usuario en 2-3 líneas qué cambió y dónde. Sin red de recuperación la
disciplina **sube**, no baja: ver `guide.md` → "Persistencia y la red de recuperación".

**`persistencia = comando`** — ejecuta el `persistencia_cmd` del manifiesto y reporta su resultado
con honestidad: si falla, dilo y **no des el cierre por persistido**. El comando **nunca lleva
secretos** — el manifiesto es markdown versionado y legible. Las credenciales viven en el entorno o
en el gestor de la propia herramienta, nunca en un doc del marco.

## Ritual: AUDITAR (verificar que lo escrito sigue siendo cierto)

Se dispara con "audita la documentación" / "corre el audit". **Se invoca; nunca corre solo** —
auditar es caro por naturaleza y choca de frente con la regla madre *lee poco al arrancar*.

Los otros seis rituales **escriben** documentación (abrir, checkpoint, cerrar) o mantienen el
**marco** (bootstrap, actualizar, config). Ninguno re-verifica lo ya escrito: `abrir` lee poco a
propósito, `cerrar` escribe el estado nuevo sin releer el viejo, y `config`/`actualizar` tocan el
manifiesto y la maquinaria, no el contenido de los docs. Sin AUDITAR la documentación deriva en
silencio, y **un dato obsoleto se lee como hecho** — es peor que no tener el dato.

**Dos reglas duras:**

- **El historial es inmutable.** AUDITAR **nunca** reescribe `session` ni `index`. Un registro puede
  ser la *fuente* que delata el drift, y puede contener algo que nunca llegó a su hogar: en los dos
  casos se corrige **el hogar**, no el registro.
- **Nada se reescribe en silencio.** Los errores se aplican tras confirmación en bloque; las
  preferencias se preguntan una a una.

### Alcance (qué se relee, y qué no)

Releer todo en cada auditoría no escala. Default = **incremental**:

| Entra | Por qué |
| --- | --- |
| Los docs de la **lista de arranque** | Son pocos, y son los que más caro salen si mienten: se leen sin filtro en cada sesión |
| Los **hogares** que las sesiones desde la última auditoría debieron tocar | Ahí aparece la clase 7, la invisible |
| Lo que esas sesiones declaran en "Archivos tocados" | Lo tocado hace poco es lo que más contradice a lo viejo |

El rango de sesiones sale de la última fila de `audit` (desde) y de `index` (hasta). Sin `audit_log`
no hay desde dónde contar y toda auditoría es completa. **`audit completo`** se pide a mano: primera
auditoría, después de una migración estructural, o cuando el usuario lo quiera.

Los `session` y el `index` **no son objeto de corrección**, solo fuente contra la que contrastar.

### Las ocho clases de drift

| # | Clase | Qué es |
| --- | --- | --- |
| 1 | Afirmación caducada | Era cierta al escribirse, dejó de serlo, y se sigue leyendo como hecho |
| 2 | Estado obsoleto | Hitos o fases que declaran un estado superado hace sesiones |
| 3 | Criterio refutado | Una sesión posterior demostró que el criterio falla; el doc lo sigue pidiendo igual |
| 4 | Índice desincronizado | El índice no menciona secciones que se añadieron después al detalle |
| 5 | Metadato incorrecto | Una cabecera atribuye a la sesión N algo hecho en la N+2, contra otra tabla del mismo doc |
| 6 | Bloqueo obsoleto | "Bloquea la fase X" cuando X ya arrancó, e incluso respondió parte de lo que bloqueaba |
| 7 | **Hallazgo sin hogar** | Conocimiento que se quedó en el registro de sesión o en un doc de detalle y **nunca se promovió** al doc que se lee al abrir |
| 8 | Crecimiento sin revisión | Un doc pasó de legible y nadie decidió si partirlo |

Las ocho son agnósticas de dominio, y por eso el ritual es del núcleo. Un módulo activo aporta
**detectores atados a sus roles** (software: el par `specs`↔`specs_dir` y los hogares
`gotchas`/`specs`/`architecture` — ver `modules/software/module.md`).

**La clase 7 es la que justifica el ritual.** Las otras siete se ven leyendo el doc con atención;
esta no se ve en **ningún** doc, porque el defecto es una **ausencia**: el dato existe, pero no donde
se lee. Solo aparece contrastando dos sitios. Es la regla "un hogar por dato" fallando en silencio.

**Y admite dos remedios, no uno.** Promover al doc de arranque es el reflejo, pero choca con "lee poco
al arrancar" en cuanto el dato es de **consulta** y no de **orientación**: no todo lo que falta en su
hogar tiene que leerse en cada sesión. El otro remedio es un **artefacto de consulta bajo demanda**,
que se busca con `grep` cuando hace falta y no entra en la lista de arranque. Elegir mal engorda el
arranque de todas las sesiones futuras, que es un coste que no se ve al aplicarlo.

### Detectores (sin esto, el ritual es decorativo)

Un audit que devuelve "todo se ve bien" no ha auditado. Barre primero, verifica después:

```bash
# clases 1 y 3 — afirmaciones absolutas y criterios que quizá ya no valen
grep -rniE "siempre|nunca|todos los|todas las|ningún|en ningún caso|garantiza|basta con" {base} --include="*.md"

# clases 2 y 6 — marcadores de estado y bloqueos
grep -rniE "pendiente|por confirmar|validado en|en curso|en progreso|provisional|bloquea" {base} --include="*.md"

# clase 3 — vocabulario de refutación en las sesiones del rango (fuente, no objeto)
grep -rniE "en realidad|result[oó]|falso negativo|falso positivo|no funciona|descartad|corregi" {history_dir}

# clase 5 — metadatos de sesión en cabeceras, para contrastar contra {index}
grep -rniE "sesi[oó]n [0-9]+" {base} --include="*.md"

# clase 4 — secciones reales del detalle, para contrastar con su índice
grep -n "^## " <doc de detalle>

# clase 8 — tamaño contra presupuesto
wc -l <docs vivos>
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

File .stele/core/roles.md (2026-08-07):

# core/roles.md — Roles del núcleo (fuente del mapa derivado)

> **Fuente de verdad de los roles agnósticos** del marco. De aquí se generan los dos artefactos
> derivados (lista de arranque + tabla de enrutamiento) combinando estos metadatos con el binding
> `rol → nombre` del manifiesto (`stele.config.md`). Los ids de rol son **estables y no se
> traducen**; los nombres son defaults que la config puede reescribir.

## Resolución de ruta

`ruta = {base}/[<valor del contenedor> si la ubicación nombra uno]{nombre}`, donde el valor del
contenedor es el nombre de carpeta que da el manifiesto (`history/`, `correspondencia/`…). Ubicación
`base` = directo bajo `base`; `history` o `correspondence_dir` = bajo esa carpeta. Un rol con nombre
`—` en la config está **desactivado** (no aparece en arranque ni en el mapa).

**No confundir el valor con el token.** El manifiesto guarda el nombre de la carpeta; el token
`{{history_dir}}` que usan las plantillas resuelve a la ruta completa desde la raíz, **con `base` ya
delante**. Por eso `{{history_dir}}{{index}}` es una ruta ejecutable y `{base}/{{history_dir}}…`
duplicaría `base`. Ver `SKILL.md` → "Convención de tokens".

**Ningún rol vive en el kit.** `base` (docs instanciados) y `kit` (el marco) son rutas
independientes del manifiesto: los roles se resuelven siempre bajo `base`; `{{kit}}` solo aparece
como referencia *hacia* el marco dentro de las plantillas. El `loader` es la tercera ruta y no es
un rol: se genera en la raíz. Ver `guide.md` → "Las tres rutas".

## Roles

| Rol | Nombre default | Ubicación | startup | order | Propósito |
| --- | --- | --- | --- | --- | --- |
| entry | AGENTS.md | base | obligatorio | 10 | Cómo trabajar: proceso, estructura, convenciones, arranque. Punto de entrada único. |
| state | latest.md | history | obligatorio | 30 | Dónde estamos y el próximo paso. Se **sobrescribe**; acotado. |
| handover | handover.md | history | obligatorio* | 40 | Checkpoint de trabajo en curso. *Se lee al abrir solo si su Estado ≠ `SIN_TRABAJO_ACTIVO`. |
| charter | design.md | base | on-demand | — | Por qué el proyecto es así: norte, principios, restricciones, decisiones grandes, glosario. |
| protocol | protocol.md | base | on-demand | — | Formatos y convenciones de documentación entre sesiones. |
| index | index.md | history | on-demand | — | Índice append-only de sesiones. Se lee con grep. |
| session | sesion-{NNN}-{YYYY-MM-DD}.md | history | on-demand | — | Registro por sesión. Inmutable; se lee con grep. |
| audit | audit.md | history | on-demand | — | Log append-only de auditorías de documentación. Opcional (feature `audit_log`). |
| correspondence | cartas.md | correspondence_dir | on-demand | — | Índice append-only del intercambio con el exterior, **en las dos direcciones**, con lo aceptado y **lo rechazado y por qué**. Opcional (feature `correspondence_log`). |
| letter | carta-{NNN}-{YYYY-MM-DD}.md | correspondence_dir | on-demand | — | Una carta, enviada o recibida. Numeración **única para ambas direcciones**: leer 1..N es leer la conversación. Inmutable. |
| correspondence_dir | correspondencia/ | base | contenedor | — | Carpeta del intercambio con el exterior. No es un doc. |
| history_dir | history/ | base | contenedor | — | Carpeta que agrupa state/handover/index/session. No es un doc. |
| artifacts_dir | artefactos/ | base | contenedor | — | Hogar de los **artefactos** que una sesión produce y no son documentación: scripts de un solo uso, extracciones, volcados intermedios. Subdirectorio por sesión. **No se instancia en bootstrap**: lo crea el primer artefacto. |

El patrón de numeración de `session` (`{NNN}`) vive **solo aquí**: es parte de su nombre, no un
parámetro aparte. Cambiarlo afecta únicamente a sesiones futuras (el historial es inmutable).

## Convención de nombres: minúscula por defecto

**MAYÚSCULA solo donde la impone algo externo.** Los defaults de arriba están en minúscula porque la
mayúscula solo señala mientras es rara: cuando la lleva todo, deja de distinguir y solo queda el
volumen. Reservada así, **vuelve a significar algo — "este nombre no lo elegimos nosotros"**.

Los que la conservan, y por qué:

| Nombre | Quién lo impone |
| --- | --- |
| `README.md`, `LICENSE` | Convención universal y las plataformas de código |
| `CLAUDE.md` (u otro `loader`) | La herramienta lo busca por ese nombre exacto |
| `AGENTS.md` (el `entry`) | Varios agentes lo auto-cargan de la raíz (ver `{{kit}}/GUIDE.md` → acoplamiento) |
| `SKILL.md` | El layout `skill`: al vendorizar el kit en `.claude/skills/…`, Claude Code busca ese nombre |

**`SKILL.md` es el que más fácil se cuela en un barrido de minúsculas**, porque no lo impone la
plataforma sino un layout — y bajarlo rompe ese layout **en todo adoptante sin dar error en ningún
sitio**.

Y una consecuencia que ya mordió: **`base` no se llama como el kit.** Ver la tabla de layouts en
`{{kit}}/SKILL.md` — un nombre que es subcadena de otro no solo confunde a las personas, hace que una
sustitución textual corrompa en silencio.

## Triggers (enrutamiento: "necesito… → hogar")

| Rol | Necesito… |
| --- | --- |
| entry | cómo trabajar, proceso, reglas operativas, arranque |
| charter | por qué: principios, decisiones grandes, restricciones, glosario |
| protocol | formatos/reglas de documentación y registro |
| state | dónde estamos, próximo paso inmediato, retomar contexto |
| handover | trabajo a medias, checkpoint de un salto en curso |
| index | qué pasó y cuándo (índice de sesiones) |
| session | el detalle de una sesión concreta |
| audit | cuándo se auditó la documentación, qué salió y qué se decidió no cambiar |
| correspondence | qué se intercambió con fuera, qué se aceptó, qué se rechazó y por qué |
| letter | el texto de una carta concreta, enviada o recibida |
| artifacts_dir | dónde poner un script de un solo uso, una extracción o un volcado intermedio |

## Notas

- **`startup` + `order`** alimentan la *lista de lectura de arranque* (roles `obligatorio` ordenados
  por `order`, nombre resuelto por la config). Los `on-demand` van a la nota "lee lo demás con grep".
- **`triggers`** alimenta la *tabla de enrutamiento* del mapa de documentación.
- Los módulos activos aportan más roles (ver `modules/<mód>/roles.md`); se fusionan con estos por
  `order`. Que `gotchas` sea obligatorio-de-arranque, por ejemplo, lo aporta el módulo `software`.
- **Varios roles nacen del uso y no del scaffold**, y por la misma razón: una carpeta o un log vacíos
  en cada adopción son peso muerto, y su **ausencia es el dato**.
  - **`audit`** lo crea la primera auditoría que corre; que no exista significa que el proyecto nunca
    se ha auditado.
  - **`correspondence`, `letter` y `correspondence_dir`** los crea la primera carta, en cualquiera de
    las dos direcciones; que no existan significa que este proyecto no ha intercambiado nada con
    fuera.
  - **`artifacts_dir`** lo crea el primer artefacto; que no exista significa que ninguna sesión ha
    necesitado producir nada fuera de la documentación.
- **La correspondencia tiene la misma forma que el historial**, y por eso no hay nada nuevo que
  aprender: un **índice** (`correspondence`, como `index`), un **archivo por pieza** (`letter`, como
  `session`, inmutable y numerado) y su **carpeta** (`correspondence_dir`, como `history_dir`). La
  única diferencia real es que la numeración de `letter` **no distingue dirección**: una carta
  enviada y su respuesta son consecutivas, así que el hilo es el orden.
- **Los tres contenedores no se comportan igual en el enrutamiento.** `history_dir` y
  `correspondence_dir` **agrupan roles** y no tienen trigger propio: nadie pregunta dónde va
  `history/`, se pregunta por `state`, por `index` o por `letter`. `artifacts_dir` **sí** lo tiene,
  porque él mismo es el destino: no contiene roles sino archivos sueltos, y "dónde pongo este script"
  es exactamente una pregunta de enrutamiento.

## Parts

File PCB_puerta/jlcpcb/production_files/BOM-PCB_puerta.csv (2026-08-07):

Comment | Designator | Footprint | LCSC | Quantity
220 | R21 | R_0603_1608Metric_Pad0.98x0.95mm_HandSolder |  | 1
220uF/16V | C3 | CP_Elec_6.3x7.7 |  | 1
10K2 | R6 | R_0603_1608Metric |  | 1
MB6S | D2 | TO-269AA |  | 1
1nF | C7 | C_0603_1608Metric |  | 1
51K | R3 | R_0603_1608Metric |  | 1
4K7 | R16 | R_0603_1608Metric |  | 1
100 | R28 | R_Axial_DIN0414_L11.9mm_D4.5mm_P15.24mm_Horizontal |  | 1
10K1 | R5 | R_0603_1608Metric |  | 1
10uH | L1 | L_0603_1608Metric |  | 1
680 | R24 | R_0603_1608Metric_Pad0.98x0.95mm_HandSolder |  | 1
0R | R20 | R_0603_1608Metric |  | 1
51K | R2 | R_0603_1608Metric |  | 1
BT138-800 | Q1 | TO-220-3_Vertical |  | 1
10K | R15 | R_0603_1608Metric |  | 1
10K | R8 | R_0603_1608Metric |  | 1
LTV-817S | U6 | SMDIP-4_W9.53mm |  | 1
10nF/250V | C15 | C_Disc_D7.5mm_W5.0mm_P7.50mm |  | 1
1nF | C12 | C_0603_1608Metric |  | 1
PC817 | U2 | SMDIP-4_W9.53mm |  | 1
10D271K | RV1 | RV_Disc_D12mm_W3.9mm_P7.5mm |  | 1
680 | R10 | R_0603_1608Metric |  | 1
LED | D1 | LED_0805_2012Metric |  | 1
4K7 | R12 | R_0603_1608Metric |  | 1
10uF/16V | C5 | CP_EIA-3216-10_Kemet-I |  | 1
10K | R13 | R_0603_1608Metric |  | 1
330 | R22 | R_0603_1608Metric_Pad0.98x0.95mm_HandSolder |  | 1
MMBT3904 | Q2 | SOT-23 |  | 1
SS34 | D6 | D_SMA |  | 1
750 | R25 | R_0603_1608Metric_Pad0.98x0.95mm_HandSolder |  | 1
MMBT3904 | Q3 | SOT-23 |  | 1
SW_Push | SW2 | SW_Tactile_SPST_NO_Straight_CK_PTS636Sx25SMTRLFS |  | 1
SW_Push | SW3 | SW_Tactile_SPST_NO_Straight_CK_PTS636Sx25SMTRLFS |  | 1
0.5A/12V | F2 | Fuse_0805_2012Metric |  | 1
1K | R1 | R_0603_1608Metric |  | 1
4K7 | R7 | R_0603_1608Metric |  | 1
ESP32-S3-WROOM-1U-N8R8 | U1 | ESP32-S3-WROOM-1 |  | 1
220 | R4 | R_0603_1608Metric |  | 1
0R33 | R11 | R_0603_1608Metric |  | 1
10K | R17 | R_0603_1608Metric |  | 1
10uF/16V | C11 | CP_EIA-3216-10_Kemet-I |  | 1
220uF/10V | C14 | CP_Elec_6.3x7.7 |  | 1
HLK-PM01 | PS1 | CONV_HLK-PM01 |  | 1
680 | R9 | R_0603_1608Metric |  | 1
1A/250V | F1 | Fuseholder_Clip-5x20mm_Littelfuse_445-030_Inline_P20.50x5.20mm_D1.30mm_Horizontal |  | 1
USB_C_Receptacle_USB2.0_16P | J1 | USB_C_Receptacle_GCT_USB4105-xx-A_16P_TopMnt_Horizontal |  | 1
MC33063AD | U3 | SOIC-8_3.9x4.9mm_P1.27mm |  | 1
100nF/250V | C1 | C_Disc_D10.5mm_W5.0mm_P7.50mm |  | 1
100nF | C2 | C_0603_1608Metric |  | 1
330pF | C9 | C_0603_1608Metric |  | 1
330 | R23 | R_0603_1608Metric_Pad0.98x0.95mm_HandSolder |  | 1
Conn_01x04 | J4 | JST_PH_B4B-PH-K_1x04_P2.00mm_Vertical |  | 1
Conn_01x07_Socket | J6 | PinHeader_1x07_P2.54mm_Vertical |  | 1
SANYOU_SRD_Form_C | K1 | Relay_SPDT_SANYOU_SRD_Series_Form_C |  | 1
1nF | C10 | C_0603_1608Metric |  | 1
20K | R18 | R_0603_1608Metric |  | 1
100nF | C4 | C_0603_1608Metric |  | 1
LED | D3 | LED_0805_2012Metric |  | 1
SANYOU_SRD_Form_C | K2 | Relay_SPDT_SANYOU_SRD_Series_Form_C |  | 1
SS34 | D5 | D_SMA |  | 1
1nF | C13 | C_0603_1608Metric |  | 1
LTV-817S | U5 | SMDIP-4_W9.53mm |  | 1
SW_Push | SW1 | SW_Tactile_SPST_NO_Straight_CK_PTS636Sx25SMTRLFS |  | 1
1K | R26 | R_0603_1608Metric_Pad0.98x0.95mm_HandSolder |  | 1
MOC3021M | U4 | DIP-6_W7.62mm_LongPads |  | 1
220uF/10V | C8 | CP_Elec_6.3x7.7 |  | 1
10K | R19 | R_0603_1608Metric |  | 1
47uH | L2 | L_Changjiang_FXL0624 |  | 1
100nF | C6 | C_0603_1608Metric |  | 1
SS13 | D4 | D_SMA |  | 1
1K | R27 | R_0603_1608Metric_Pad0.98x0.95mm_HandSolder |  | 1
Screw_Terminal_01x07 | J2 | TerminalBlock_MaiXu_MX126-5.0-07P_1x07_P5.00mm |  | 1
Conn_01x04 | J3 | JST_PH_B4B-PH-K_1x04_P2.00mm_Vertical |  | 1
Conn_01x04 | J5 | Molex_KK-254_AE-6410-04A_1x04_P2.54mm_Vertical |  | 1
1K | R14 | R_0603_1608Metric |  | 1

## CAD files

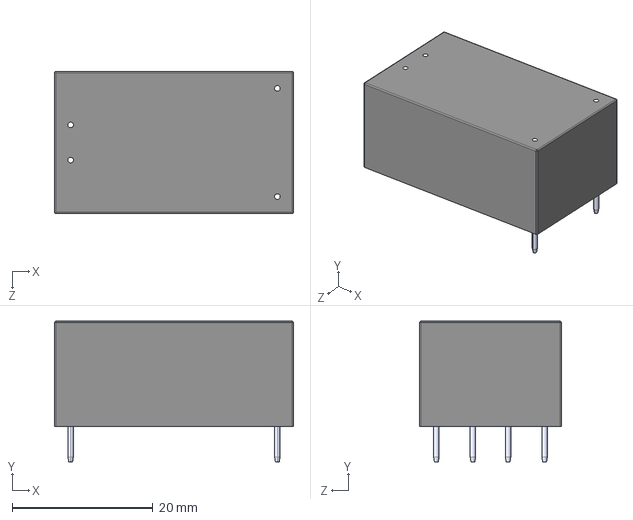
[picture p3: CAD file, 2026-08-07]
PCB_puerta/HLK-PM01.STEP
34.0 x 20.0 x 20.2 mm

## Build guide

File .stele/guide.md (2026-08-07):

# GUIDE — fundamentos del marco (por qué, y las fronteras)

> Referencia. Se lee una vez. La operación diaria está en `SKILL.md`. Este archivo explica el
> *por qué* de cada regla, para que quien adapte el marco no rompa lo que lo hace funcionar.
> Es **agnóstico de dominio**: sirva el proyecto para software, para preparar materiales, planear
> actividades o investigar. Lo específico de software vive en `modules/software/`.

## El problema que resuelve

Los agentes no recuerdan entre sesiones. Sin disciplina, el contexto se recupera de dos maneras
malas: (a) leyendo montañas de historial cada vez (coste de tokens que crece sin límite), o (b)
reconstruyéndolo desde el diff (frágil, lento, se pierde el *por qué*). En un caso real, el archivo
de "estado" creció a ~53K tokens porque cada cierre *prependía* un resumen sin podar — y se leía
entero al arrancar cada sesión.

## Los seis pilares (agnósticos)

1. **Continuidad.** El objetivo es que cualquier agente retome sin reconstruir contexto.
2. **Estado ≠ historial.** El *estado* (dónde estamos) se **sobrescribe** y vive acotado; el
   *historial* (qué pasó) es **append-only** en archivos que **no se releen** salvo búsqueda puntual.
3. **Un hogar por dato.** Cada hecho vive en UN documento; los demás apuntan, no copian. Nada se
   duplica ni se desincroniza, y siempre sabes dónde buscar (y dónde escribir).
4. **Arranque barato.** El set de apertura es pequeño y fijo *a propósito*; todo lo demás es bajo
   demanda con `grep`.
5. **Decisiones a su hogar.** Lo que perdura se lleva a su documento hogar en el momento en que se
   decide, no solo al historial.
6. **Curación.** Los documentos vivos se **podan**: una entrada obsoleta se borra (su rastro queda
   en el historial). No se acumula.

## Tres rituales base + tres de ciclo de vida + uno de verificación + dos de correspondencia

- **Abrir** (ponerse al día, barato) · **Checkpoint** (dejar el salto en curso a salvo antes de un
  cambio interrumpible) · **Cerrar** (dejar registro durable).
- **Bootstrap** (instanciar el marco en un proyecto), **Actualizar** (traer una versión nueva del kit
  y reconciliar la instancia) y **Config** (adaptar nombres/parámetros).
- **Auditar** (verificar hacia dentro que lo escrito sigue siendo cierto).
- **Contrastar** (recibir de fuera un informe sobre tu trabajo y decidir qué entra) y **Remitir**
  (escribir hacia fuera lo que encontraste y no es tuyo).

Detalle operativo de los nueve: `SKILL.md`.

**Por qué el séptimo existe.** Los seis primeros se reparten en dos grupos —los que **escriben**
documentación y los que mantienen el **marco**— y ninguno de los dos re-verifica el **contenido** ya
escrito: `abrir` lee poco a propósito, `cerrar` escribe el estado nuevo sin releer el viejo, y
`config`/`actualizar` tocan el manifiesto y la maquinaria, no lo que dicen los docs. El hueco solo se
nota con el uso prolongado, y lo que crece dentro es **drift**: afirmaciones que fueron ciertas y
dejaron de serlo. **Un dato obsoleto se lee como hecho**, así que documentación derivada es peor que
documentación ausente — la ausencia se nota, el drift no.

Auditar es, en la práctica, el ritual de dos pilares que hasta ahora solo eran buenas intenciones: la
**curación** (pilar 6) y **un hogar por dato** (pilar 3). El fallo más caro que encuentra no es una
frase falsa sino una **ausencia**: conocimiento que se quedó en un registro de sesión y nunca se
promovió al doc que se lee al abrir. Eso no se ve leyendo ningún documento; solo aparece contrastando
dos. Por eso no puede ser un efecto secundario de otro ritual, y por eso **se invoca**: auditar es
caro por naturaleza, y meterlo en `abrir` rompería el pilar 4 (arranque barato).

**Por qué existen los dos de correspondencia.** Mismo test, otra respuesta. Los siete anteriores miran
**hacia dentro**: escriben la documentación del proyecto, mantienen su marco, o re-verifican lo ya
escrito. Ninguno maneja el trato con **el exterior**. Visto como flujo, la asimetría salta:
*actualizar* es cómo un cambio del kit **baja** hasta quien lo usa, y no existía el camino de
**vuelta** — cómo un hallazgo de quien lo usa **sube**. Y no es cosa de kits: cualquier proyecto recibe
informes sobre su trabajo (la revisión de un director, los resultados de un socio, la evaluación de un
curso) y encuentra cosas que pertenecen a otro.

**Contrastar** es la vía de entrada de **mayor consecuencia** que tiene un proyecto: lo que pasa por
ahí se incorpora al producto y viaja a todo el que lo use. Un mal audit cuesta una tarde; un informe
mal integrado se publica. Por eso su regla central no es *aceptar* sino **contrastar**: el diagnóstico
de quien reporta viaja —tiene el caso, que tú no ves—, pero el remedio hay que volver a derivarlo desde
tu diseño —que él no ve—.

**Remitir** es el espejo, y su parte difícil no es escribir sino **darse cuenta**. El disparador sale
de generalizar la clase 7 de auditar: una trampa que estás a punto de archivar en tus gotchas y que en
realidad habla de *la herramienta que usas* no tiene su hogar en tu repo — ahí no arregla nada.

**El canal se queda fuera del marco, y es una decisión, no un olvido.** El kit estandariza **la
carta**, nunca el transporte: así viaja por correo, por un issue, por un PR, o pegada en la sesión de
otro agente, y **copiar y pegar es el suelo que siempre funciona**, sin pedirle a nadie que aprenda
git. Hay una excepción que no costó nada: como *actualizar* ya se trae el árbol entero del kit, un
buzón dentro del kit **baja solo** con la actualización. La bajada era gratis; la subida necesita
cartero.

## Arquitectura: núcleo · módulos · config

El marco es **modular y configurable**, en tres capas:

- **Núcleo** (`core/`) — roles + rituales + principios, agnósticos de dominio. Se define sobre
  **ids de rol estables** (`entry`, `charter`, `protocol`, `state`, `handover`, `index`, `session`),
  no sobre nombres de archivo. Fuente de los roles: `core/roles.md`.
- **Módulos** (`modules/<nombre>/`) — paquetes de roles + disciplinas para un tipo de trabajo. El
  primero es `software` (añade `specs`/`architecture`/`gotchas`/`effort` + convenciones + la regla
  del checkpoint antes del primer archivo de código). Un proyecto no-software simplemente no lo activa.
- **Config** (`stele.config.md`, en la raíz del proyecto) — **fuente única** que enlaza `rol →
  nombre`, activa módulos y fija toggles/presupuestos/wording/idioma y las **tres rutas**. Todo lo
  accionable en tablas. De aquí se **generan** dos derivados: el auto-arranque y el mapa de
  documentación.

**La frontera núcleo/módulo** es una sola pregunta: el núcleo modela el **proceso de continuidad**
(dónde estamos, qué pasó, qué quedó a medias — agnóstico); un módulo modela el **objeto del trabajo**
(el codebase, el corpus, el plan). Por eso `specs`, `architecture` y `gotchas` son roles de módulo
aunque suenen universales: un proyecto de planeación los dejaría vacíos, y un documento vacío es
peso muerto en cada adopción. El corolario práctico es que activar `software` no exige un
compilador, sino un producto con estructura y decisiones por feature — un kit de documentación
también lo es (ver `modules/software/module.md`).

**Separar rol de nombre** es lo que hace configurable el marco: los rituales y punteros se expresan
en roles; la config los resuelve a nombres. Renombrar es una operación del ritual `config`, no un
find/replace a ciegas — es segura porque el marco se auto-documenta.

La misma separación, aplicada una tercera vez, resuelve un problema distinto: **el vocabulario del
marco no es el vocabulario de la conversación**. Los ids, las claves del manifiesto y los estados se
*parsean*, así que son contrato y no se traducen; pero el saludo, los ecos y los informes no los
consume ninguna máquina. Ahí el agente habla **en llano y nombra el archivo** (`SKILL.md` → "Cómo se
le habla al usuario"). No hace falta un parámetro: como el nombre del archivo va siempre entre
paréntesis, un usuario técnico no pierde precisión y uno que no lo es no tiene que aprenderse
`handover` para saber que quedó trabajo a medias. Lo que la regla **no** permite es suavizar el
hecho: si algo quedó a medias o dos docs se contradicen, se dice.

## Las tres rutas: `kit` · `base` · `loader`

La misma separación aplica a las **ubicaciones**. Hay tres, independientes entre sí, todas en la
sección Rutas del manifiesto:

| Ruta | Default | Qué es | Ciclo de vida |
| --- | --- | --- | --- |
| `kit` | `.stele` | El marco vendorizado: `SKILL.md`, `guide.md`, `core/`, `modules/`. | **Reemplazable**: se sustituye entero con el ritual ACTUALIZAR. |
| `base` | `.` | Los docs instanciados (los roles) y el `history_dir`. | **Tuyo**: crece cada sesión, se versiona, no se regenera jamás. |
| `loader` | `CLAUDE.md` | El auto-arranque en la raíz. | **Derivado por bloque**: se regenera el bloque del marco, no el archivo. |

Por qué son tres parámetros y no uno: **`kit` y `base` tienen ciclos de vida opuestos**. Uno se tira
y se reemplaza entero al actualizar; el otro es el trabajo acumulado del proyecto y no puede perderse
nunca. Confundirlos no es un problema estético de layout — es lo que hace que una actualización del
marco se lleve por delante el historial. De ahí el **invariante duro: `base` nunca dentro de `kit`**
(ni iguales). El caso inverso, `kit` dentro de `base`, es legal pero se avisa: contamina los `grep`
del ritual de apertura con plantillas del marco.

**Modo auto-hospedado** (`kit = .`): el repo del propio marco, donde el kit no se vendoriza sino que
se desarrolla en sitio. Ahí el invariante se relaja — nunca hay un borrado del kit que pueda llevarse
los docs — y `base` es un subdirectorio suyo. Es el único caso en que el kit **es el producto** del
proyecto: los docs de `base` hablan *sobre* el marco, igual que en un proyecto de software hablan
sobre el código, y no se confunden con él.

`loader` es tercero porque el nombre del archivo de auto-arranque depende del **agente**, no del
proyecto: `CLAUDE.md` para Claude Code, `AGENTS.md` para otros, `.github/copilot-instructions.md`
para Copilot. Aislarlo mantiene agnóstico casi todo lo demás — con una excepción que conviene saber:
si el `entry` conserva su nombre por defecto `AGENTS.md`, **también** hay agentes que lo auto-cargan
desde la raíz. Entonces mover `base` fuera de la raíz les quita el `entry` sin romper nada visible,
porque el loader sigue funcionando. Es un fallo silencioso; ver el aviso de `SKILL.md` → "Layouts con
nombre".

**El loader es derivado en parte, no desechable.** Lo que genera el marco es el **bloque** entre
`STELE:INICIO` y `STELE:FIN`; el **archivo** puede ser compartido, porque muchos equipos ya tenían un
`CLAUDE.md` o un `AGENTS.md` escrito a mano antes de adoptar stele. Por eso, si existe, se modifica y
no se crea de cero: es la misma regla de adopción que rige para cualquier doc de rol. La distinción
no es teórica — tratarlo como puro derivado destruyó el `CLAUDE.md` de un proyecto real.

**Dos anclas fijas en la raíz** que no siguen a `base`: el `loader` y el manifiesto
`stele.config.md`.

El **loader** porque el agente lo carga por nombre al abrir la sesión: si se moviera, no habría quién
le dijera dónde está. El **manifiesto** porque no es un doc del proyecto, es **el resolvedor**:
`base` declara dónde viven los docs de los *roles*, y el manifiesto no es un rol — es lo que traduce
roles a nombres y rutas. Guardarlo dentro de lo que él mismo resuelve es un error de categoría, la
misma razón por la que `package.json` no vive en `src/`. Y es donde lo busca un humano, que también
lee la configuración.

La pregunta aparece sola al usar `agrupado`: *si todo lo del marco se junta, ¿por qué el manifiesto
se queda fuera?* Porque agrupar del todo es imposible — el loader nunca se mueve, así que la raíz
pasaría de dos archivos del marco a uno. Ver "Alternativas descartadas".

Las combinaciones habituales tienen **nombre** (`default`, `agrupado`, `docs`, `skill`) para poder
pedirlas y confirmarlas de un tirón; la tabla vive en `SKILL.md` → "Layouts con nombre". Son
vocabulario, no un cuarto parámetro: **no se guardan en el manifiesto**, porque el layout ya es
derivable de las tres rutas y un dato con dos hogares se desincroniza. Por eso el eco del bootstrap
lo *nombra* pero lo que se escribe son siempre las rutas.

## Persistencia y la red de recuperación

Cerrar una sesión **escribe** el registro; persistirlo es otro paso, y el marco no asume cuál. El
parámetro `persistencia` lo declara: `git` · `ninguna` (los archivos en disco son el registro) ·
`comando` (una orden que el usuario configuró: `rclone`, un empaquetado fechado, otro VCS). El
núcleo es agnóstico a propósito — un proyecto de planeación o de investigación no tiene por qué usar
git — y el ritual de cierre se resuelve contra ese parámetro.

Lo importante no es el mecanismo sino lo que se pierde sin él. **Un VCS no es solo respaldo: es la
red que permite reconstruir el *qué* cuando la documentación falla.** Sin esa red, la disciplina
documental **sube**, no baja:

- El registro de sesión pasa a ser el **único** rastro de qué cambió. "Archivos tocados" ya no puede
  listar rutas: tiene que decir qué cambió dentro de cada una, porque no habrá diff que consultar.
- La regla "revertir solo los hunks propios" **presupone que puedes identificar hunks**. Sin VCS
  degrada a "no toques lo que no escribiste en esta sesión, y ante la duda pregunta".
- El checkpoint se vuelve **más** crítico, no menos: sin `git status` ni diff, el `handover` es la
  única forma de saber qué quedó a medias tras una interrupción.

**El marco nunca implementa la persistencia**: eso sería runtime, y rompería "markdown puro". El
paso de cierre es declarativo — le dice al usuario qué hacer, o ejecuta el comando que él configuró.

**Carpeta sincronizada** (Drive, OneDrive, Dropbox) es el caso más común de `ninguna`: guardar en
disco ya *es* el respaldo, sin credenciales ni configuración. Dos trampas que hacen que no sustituya
a un VCS:

- **La sincronización no es atómica.** Versiona archivo por archivo; un cierre toca cinco a la vez y
  no se recupera el conjunto como unidad. Las tres reglas de arriba siguen aplicando igual.
- **Los conflictos rompen justo los archivos append-only.** Cerrar sesión desde dos máquinas genera
  copias en conflicto, y `index`/`effort` son precisamente los que se duplican o se pisan.

**Credenciales, nunca.** Ningún doc del marco lleva tokens, claves ni cadenas de conexión: son
markdown legible, normalmente versionado, y en un kit vendorizado hasta se copian a otros proyectos.
Un comando de persistencia nombra la herramienta; las credenciales viven en el entorno o en el
gestor de esa herramienta.

## Alternativas descartadas (para no volver a proponerlas)

- **Referencia por rol en vivo** (escribir `[state]` en los docs y resolverlo al leer): descartada.
  Markdown no tiene indirección nativa, y el marco es agente-primero: los docs instanciados llevan
  **nombres concretos y legibles**. La indirección se resuelve **una vez**, en `bootstrap`, y
  renombrar es una operación del ritual `config` — el único renombrador sancionado.
- **Roles y módulos definidos por el usuario:** fuera de alcance a propósito. La config llega hasta
  nombres, toggles, presupuestos, wording, idioma y rutas; ampliar el vocabulario de roles rompería
  que el núcleo sea la fuente del mapa derivado.
- **Mover el manifiesto bajo `base`** (para que `agrupado` deje la raíz limpia): descartado, y no
  por la circularidad aparente — esa se rompería con un puntero desde el loader. Se descarta porque
  no consigue su objetivo (el loader no puede moverse, así que la raíz queda igual de "sucia", con un
  archivo en vez de dos) y porque el manifiesto es el resolvedor, no un doc de rol. A cambio de eso
  habría que añadir una ruta más, reescribir el invariante 5 y dejar no conformes las instancias ya
  existentes. Además, alcanzarlo solo a través del loader lo haría depender de un **derivado**:
  borrarlo o renombrarlo dejaría el manifiesto localizable únicamente por búsqueda.
- **Marcador de versión del kit** (`VERSION`, changelog de migración): descartado. El **diff** dice
  *qué* cambió y dónde, que es lo único accionable; un número no dice qué migrar, hay que acordarse
  de subirlo en cada cambio del kit, y miente en cuanto alguien lo olvida — un dato derivable con un
  segundo hogar. El ritual ACTUALIZAR garantiza que el diff exista siempre, que es lo que hace
  innecesario el marcador. **La procedencia es el caso contrario y sí se guarda** (`kit_origen`, en
  Meta): de qué remoto salió tu copia no se deduce de nada — ni del árbol, ni de un diff, ni del
  `README` vendorizado, que apuntaría al upstream aunque hubieras clonado un fork. Lo derivable no se
  guarda; lo no derivable, sí. Sin `kit_origen`, ACTUALIZAR se bloquea en el primer paso.
- **Un toggle de vocabulario** (`tecnico` | `llano`, para decidir cómo le habla el agente al
  usuario): descartado. La regla de hablar en llano **y nombrar el archivo** no le quita nada a un
  usuario técnico —el nombre va igualmente entre paréntesis—, así que no hay dos públicos que
  atender, solo uno. Un toggle habría añadido un parámetro a cada adopción, una rama más en cada
  ritual y una forma nueva de quedar incoherente con el resto de la config, a cambio de una salida
  algo más corta. El vocabulario **de datos** sigue intacto: eso es lo que hace innecesario el
  parámetro.
- **`idioma` no es traducción en runtime.** Dirige qué variante de plantilla se instancia y el
  wording de los rituales, nada más; el contenido del proyecto queda como lo escribió su autor. Los
  ids de rol y los headers `##` del manifiesto son **tokens fijos que no se traducen**, para que el
  parseo nunca dependa del idioma.

## Roles y fronteras (núcleo)

El error más común al adoptar el marco es solapar documentos. Fronteras de los roles del núcleo
(nombres default entre paréntesis; la config puede cambiarlos):

- **`entry` (AGENTS.md) — cómo trabajar.** Proceso, estructura, convenciones operativas, checklists
  (como punteros). Entrada única. Incluye el *mapa de documentación* (generado). NO lleva el detalle
  de otros hogares: apunta.
- **`charter` (design.md) — por qué el proyecto es así (a gran escala).** Norte, principios,
  restricciones y no-negociables, decisiones estructurales grandes (ADR-lite, fechadas), glosario.
  Estable. Frontera: *principios transversales* aquí; *specs por feature* → módulo.
- **`protocol` (protocol.md) — formatos.** Cómo se documenta (formatos de cada archivo, topes,
  operaciones de bajo coste). Referencia de formato.
- **`state`/`handover`/`index`/`session` — el historial** (`history_dir`, history/): estado que se
  sobrescribe, checkpoint del salto en curso, índice y detalle por sesión (se leen con grep).
- **`audit` (audit.md) — la serie de auditorías**, también en `history_dir` y append-only. Opcional
  (feature `audit_log`) y **no se instancia en bootstrap**: lo crea la primera auditoría, y su
  ausencia significa que el proyecto nunca se auditó. Guarda *cuándo y con qué alcance*, no los
  hallazgos: lo que perdura de una auditoría vive en el hogar que corrigió.
- **`correspondence`/`letter`/`correspondence_dir` — el intercambio con el exterior**, con la **misma
  forma que el historial**: un índice, un archivo por carta (inmutable, numerado) y su carpeta.
  Opcional (feature `correspondence_log`) y **no se instancia en bootstrap**: lo crea la primera
  carta. La numeración **no distingue dirección**, así que leer 1..N es leer la conversación y una
  carta sin respuesta detrás es un hilo abierto. El índice guarda lo que ningún otro doc guarda: **qué
  se rechazó y por qué** — un descarte razonado evita volver a discutirlo y le dice a quien escribió
  cómo calibrar la próxima.
- **`artifacts_dir` (artefactos/) — lo que la sesión produce y no es documentación:** scripts de un
  solo uso, extracciones, volcados. Un subdirectorio por sesión, y **tampoco se instancia en
  bootstrap**: lo crea el primer artefacto. Existe porque el historial guarda el *qué* y no el *cómo*,
  y un script de un solo uso escrito en el temporal privado del agente se lleva el *cómo* consigo —
  con `persistencia = ninguna`, la única reconstrucción posible. Ver `SKILL.md` → Precedencia.

Los roles que añade un módulo se describen en su `modules/<nombre>/roles.md` (p. ej. software:
`gotchas`, `specs`, `architecture`, `effort`).

## Presupuestos de tamaño (lo que mantiene barato el arranque)

| Rol | Tope objetivo | Al superarlo |
| --- | --- | --- |
| `state` | ~100 líneas | Podar; es estado, no historia |
| `handover` | ~50 líneas | Solo lo del salto activo |
| `charter` | ~200 líneas | Extraer una decisión a un tema del módulo + link |
| `session` | sin tope | Es histórico; se lee con grep, no al arrancar |

Los presupuestos son parámetros de la config (sección Presupuestos); los módulos pueden añadir los
suyos (p. ej. software: sección de `gotchas` por subsistema ~150-200 líneas).

**Un presupuesto excedido se decide, no se recorta.** El tope es un **umbral de olor**, no un límite:
lo que pide al cruzarse es una decisión, y hay dos salidas legítimas. Podar, si al mirarlo sobra algo
—que es el caso corriente—. O **subirlo con `config`** para ese proyecto, si el doc de verdad necesita
ese tamaño: un proyecto grande con varios frentes en paralelo puede necesitar un `handover` que no cabe
en el default, y forzarlo a caber destruye justo lo que el doc existe para conservar. Lo que no vale es
recortar hasta cuadrar el número: eso deja el tope intacto y el contenido mutilado, y además borra la
señal — un presupuesto que siempre se cumple porque se recorta ya no mide nada.

Y antes de subirlo, mira **por qué** no cabe: un `handover` que se desborda porque lleva tres saltos en
paralelo no está diciendo que el tope sea pequeño, sino que se está usando para algo que no es un
checkpoint. Los dos diagnósticos piden arreglos distintos.

## Por qué la regla dura del checkpoint

Una sesión puede cortarse en cualquier momento (límite de uso, cierre de la herramienta,
intervención del usuario). Si eso pasa con trabajo a medias y `handover` diciendo "sin trabajo
activo", la siguiente sesión reconstruye el contexto desde el diff — caro y con pérdida del *por
qué*. Escribir el checkpoint (~20 líneas) **antes** del cambio interrumpible cuesta siempre menos.
Por eso es regla dura, no un juicio. El módulo software la especializa a "antes del primer archivo
de código"; el núcleo usa el `checkpoint_trigger` genérico configurable.

## Adaptar el marco a un proyecto

- **Bootstrap** instancia el marco (ver `SKILL.md` → ritual BOOTSTRAP). Detecta greenfield vs
  adopción (si ya hay docs, los mapea sin sobrescribir), y **hace eco del layout resuelto — las tres
  rutas — antes de escribir nada**: corregir la interpretación cuesta cero antes del scaffold y caro
  después.
- **Actualizar** trae una versión nueva del kit y reconcilia la instancia contra ella. Lo importante
  no es copiar archivos: es **leer el diff** entre el kit viejo y el nuevo y decidir qué implica
  (¿roles nuevos? ¿cambió la forma del manifiesto?). Por eso la versión nueva se trae **al lado**, no
  encima: el diff necesita las dos versiones, y traerlas en ese orden convierte la seguridad en una
  propiedad de la secuencia en vez de en una disciplina que hay que recordar. Nunca toca `base`: una
  plantilla nueva no reinstancia tus docs.
- **Config** cambia nombres, módulos, toggles, presupuestos, wording, idioma y las tres rutas — sin
  romper referencias, porque regenera los derivados.
- **Escala la ceremonia.** `effort` y la numeración `sesion-NNN` son opcionales; un proyecto pequeño
  puede empezar solo con el núcleo e ir sumando.
- **Cura, no acumules.** Los documentos vivos se podan; lo superado ya vive en el historial.

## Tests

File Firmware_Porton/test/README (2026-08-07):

This directory is intended for PlatformIO Test Runner and project tests.

Unit Testing is a software testing method by which individual units of
source code, sets of one or more MCU program modules together with
associated control data, usage procedures, and operating procedures,
are tested to determine whether they are fit for use.

More information about PlatformIO Unit Testing:
- https://docs.platformio.org/page/plus/unit-testing.html

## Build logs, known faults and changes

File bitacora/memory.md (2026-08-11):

# memory.md — Gotchas técnicos no evidentes en el código

> **Hogar único** de las trampas y convenciones no evidentes al leer el código (las que un agente
> debe respetar al escribir). Lectura obligatoria al inicio de sesión, tras `AGENTS.md`.
> NO lleva: contexto de negocio / decisiones de producto (→ `requirements.md`), principios (→
> `design.md`), proceso (→ `AGENTS.md`). Para eso, apunta.
>
> Se edita incrementalmente pero se **cura**: una entrada resuelta u obsoleta se **borra** (su
> rastro queda en el historial). Si una sección de subsistema supera ~150-200 líneas, extraerla a
> un tema de `requirements.md` con un resumen de 1-3 líneas + link aquí.

---

## Stack y versiones

- **PlatformIO**, entorno `esp32-s3-devkitc-1`, framework `arduino`, USB CDC nativo habilitado
  desde el arranque (`ARDUINO_USB_MODE=1`, `ARDUINO_USB_CDC_ON_BOOT=1` en `platformio.ini`).
  Verificado en esta sesión: `pio run` compila (Flash 7.9%, RAM 5.9%).
- **Board real:** el módulo es `ESP32-S3-WROOM-1U-N8R8`. **Confirmado contra hardware real**
  (sesión 006): `pio run -t upload --upload-port COM8` cargó sin problemas; `esptool` identificó
  el chip como ESP32-S3 (QFN56, rev v0.2) con **8MB PSRAM embebida**, consistente con el módulo
  real. El entorno `esp32-s3-devkitc-1` (placa de referencia genérica) funciona tal cual, sin
  necesidad de ajustar `board_build.*` — no se detectaron problemas de tamaño de flash/PSRAM.
- **USB nativo confirmado:** el puerto enumera con VID:PID `303A:1001` (Espressif) — el USB CDC
  configurado en `platformio.ini` funciona; no es un puente serie genérico.
- **Enlazar la librería `WiFi.h` infla el binario notablemente aunque solo se use para apagar el
  radio** (`WiFi.mode(WIFI_OFF)` en `apagarRadios()`, sesión 008): Flash pasó de ~8% a ~20%, RAM
  de ~6% a ~13% en esta build. Sigue sobrando margen, pero si en algún momento el espacio se pone
  ajustado, este es el primer lugar a revisar.

## Firmware (`Firmware_Porton/`)

**Contrato de pines confirmado por el usuario** (sesión 003): tabla completa y sistema de potencia
en [`temas/hardware-esp32-s3.md`](temas/hardware-esp32-s3.md), resumen en `requirements.md` §2.
Diseño de la máquina de estados (sesión 004) en `requirements.md` §3/§4 y `architecture.md`.

- **Los relevos son activos en LOW** y **solo se escriben desde `seleccionarSentido()`** (en
  `src/porton.cpp`) — nunca con `digitalWrite` directo en otro lado. Esa función es el interlock:
  escribe los dos pines juntos, así que nunca quedan ambos en `LOW`. Si se agrega código nuevo que
  necesite mover el motor, pasar por ahí (o por `detenerMotor()`), no escribir los relevos aparte.
- **`TRIGGER` (disparo del TRIAC, `BT138-800`) es activo en LOW.** Desde la sesión 007 ya **no**
  se mantiene fijo en `LOW`: se pulsa por `PULSO_TRIAC_US` (200us) en cada semiciclo, en el
  momento que decide el retardo de fase (`delayDisparoActualUS`) — ver "Disparo del TRIAC" más
  abajo. Se habilita recién `RELAY_SETTLE_MS` después de elegir el relevo, nunca junto con él.
- **`LED` es activo en LOW** (nivel 0 = encendido).
- **`FC_OPEN`/`FC_CLOSE` usan `INPUT_PULLUP`.** Final de carrera activado se lee como `LOW`; la
  lógica comprueba con `!digitalRead(FC_OPEN)`. Se leen por *polling* (no por interrupción) — a
  propósito: al eliminarse los bloqueos del `loop()`, el polling es lo bastante rápido y evita la
  complejidad de debounce en ISR para un reed switch mecánico.
- **`D0` mueve, `D2` resetea `ERROR`** (`D1`/`D3` sin rol, ver `requirements.md` §4). Cada botón
  tiene su propio detector de flanco/antirrebote (`botonD0Presionado()`/`botonResetPresionado()`
  en `porton.cpp`) — no comparten estado, a propósito: son semánticamente independientes (uno
  opera, el otro solo reconoce una falla) y podrían presionarse casi al mismo tiempo. `D2` se
  consume siempre (todas las iteraciones), aunque solo actúa estando en `ERROR` — si no se
  consumiera igual, se perdería el flanco si el usuario lo presiona mientras el portón está en
  movimiento.
- **`ENCA`/`ENCA2` se leen por interrupción (`attachInterrupt`, `CHANGE`)**, ambos alimentan el
  mismo timestamp de detección de atasco (`ultimoPulsoEncoderISR`, `requirements.md` §3) — no
  decodifican dirección ni cuentan posición, solo "hubo un pulso". Las ISR llaman `millis()` —
  patrón estándar en el core Arduino-ESP32 (a diferencia de AVR clásico).
- **Hardware: `ENCA`/`ENCB` tienen un problema real de resistencias de pull-up en el circuito de
  entrada** (encontrado por el usuario en la sesión 006, en banco). No es un problema de
  firmware; hoy no aportan pulsos. **`ENCA2` (sensor Hall en `GPIO44`) ya es la fuente real y
  confirmada** de detección de atasco (sesión 006: 0 pulsos con el motor quieto, pulsos reales
  con el motor girando, y la detección de atasco ya se probó en hardware). Se eligió `GPIO44` y
  no `GPIO43` a propósito: el ESP32-S3 solo *transmite* por `GPIO43` (boot log, volcados de
  excepción/crash), nunca por `GPIO44` — como entrada, `GPIO44` queda más "silencioso" desde el
  arranque. Ninguno de los dos interfiere con `Serial` (usa el USB CDC nativo, no esta UART).
  `INPUT_PULLUP` asumido como para un sensor Hall típico de salida open-collector — a confirmar
  contra el datasheet del sensor puntual. Si se arregla el hardware de `ENCA`, vuelve a sumar
  sin más cambios (las dos ISR alimentan el mismo timestamp).
- **`ZCROSS`: resuelto el sobre-conteo (sesión 007).** Señal real limpia a ~120,8 Hz (confirmada
  por osciloscopio, sesión 006). El firmware contaba ~231-237/s con `ZCROSS_DEBOUNCE_US = 1000` —
  **subir el antirrebote a 3000us lo dejó en 120/s exactos.** El motivo de subirlo no fue el
  conteo en sí: con el disparo de fase real (sesión 007), un flanco espurio cercano al real podía
  armar el `esp_timer` del TRIAC dos veces para el mismo cruce, y 1000us no alcanzaba para
  filtrarlo.
- **Disparo del TRIAC por ángulo de fase, sincronizado a `ZCROSS` (sesión 007) — CONFIRMADO
  funcionando en el portón real (sesión 008), en potencia fija.** Mecanismo: `isrZcross()` arma
  `timerDisparo` (`esp_timer`) con el retardo de fase actual; su callback pulsa `TRIGGER` y arma
  `timerPulso` para soltarlo tras `PULSO_TRIAC_US`. Llamar `esp_timer_start_once()`/
  `esp_timer_stop()` desde una ISR de GPIO real (`isrZcross()`) **sí funciona** en esta build —
  quedaba como "sin verificar" en la sesión 007, ya validado con el motor real moviéndose.
  - **`ESP_TIMER_ISR` (dispatch en contexto de interrupción real) sigue sin estar disponible en
    esta build** de Arduino-ESP32 (falla la compilación al pedirlo) — los dos `esp_timer` corren
    en dispatch `ESP_TIMER_TASK` (por defecto). El jitter que eso pueda meter **no impidió** que
    el mecanismo funcionara bien en la práctica.
  - **Hallazgo clave (sesión 008): disparar muy cerca del cruce por cero (~100% de potencia, ~6,5°)
    no engancha el TRIAC de forma confiable con esta carga inductiva** — el motor directamente no
    se movía a ese nivel. A partir de ~90% (~46°) sí enganchaba. Es la explicación más probable de
    por qué la rampa de arranque original (que pasaba por la zona cercana al 100% al llegar a
    velocidad de crucero) generaba paradas falsas por "atasco": enganche inconsistente ciclo a
    ciclo = pulsos de torque irregulares, no potencia pareja. **La hipótesis de la sesión 007**
    (el motor de inducción no muestra el corte de fase en velocidad, solo en torque) **queda sin
    resolver y ya no es la explicación principal** — este hallazgo de enganche es más concreto y
    concuerda con los datos.
  - **`PULSO_TRIAC_US` subido de 200 a 500us (sesión 008)** — pulso de gate más largo, para ayudar
    al enganche cerca del cruce por cero. El retardo de disparo y el ancho del pulso son
    independientes (el pulso puede durar más que el retardo).
  - **Release (sesión 008): rampa de arranque DESACTIVADA, potencia fija al 85%**
    (`POTENCIA_MOTOR_PCT` en `porton.h`) — primer nivel que movió el portón de punta a punta sin
    falsos atascos. La rampa (`RAMPA_ARRANQUE_MS`/`actualizarRampa()`) sigue en el código, sin
    usar. Detalle completo en `requirements.md` §5.
- **UART de depuración: confirmado en `GPIO43` (TXD0) / `GPIO44` (RXD0)**, hacia un conector
  auxiliar en la placa (confirmado por el usuario, sesión 005) — **no** hay conflicto con
  `TRIGGER` (`GPIO21`). El comentario del `.ino` original (`// HW UART TXD pin IO21`) estaba
  desactualizado/equivocado; no se arrastró a `porton.h`. Con el USB CDC habilitado
  (`ARDUINO_USB_CDC_ON_BOOT`), `Serial` usa el USB nativo, así que esta UART física queda libre
  para depuración aparte si hace falta (no está en uso desde el firmware todavía).
- **`comando` se maneja por caracter ASCII** (`'0'`-`'7'`) vía `Serial`; es la interfaz de pruebas
  manuales, no un protocolo binario. Los comandos `1`/`2`/`3` reusan `seleccionarSentido()`/
  `detenerMotor()`, así que el interlock de relevos aplica también en modo manual.
- **Contador de trayecto (`contadorTrayecto`/`trayectoActivo`/`sentidoTrayecto`) tiene su propio
  `portMUX_TYPE` (`muxTrayecto`), separado de `muxPulsos`** — a propósito: `muxPulsos` solo existe
  si `DEBUG_PULSOS` está activo, y el contador de trayecto es una función real, no diagnóstica.
  **Todas** las escrituras a `trayectoActivo` deben pasar por `muxTrayecto` (se encontraron y
  corrigieron dos que no lo hacían, en la sesión 008) — aunque sea un `bool` de una sola escritura
  "atómica" en la práctica, romper el patrón ahí invita a que el próximo cambio sí introduzca una
  condición de carrera real.
- **`ultimaLlegadaConfirmada`** (sesión 008) guarda el último `ABRIENDO`/`CERRANDO` que llegó de
  verdad a su fin de carrera — no confundir con `doorLastStd` (que se actualiza en **cada**
  arranque de movimiento, llegue o no a destino, y hoy no se lee en ningún lado). Es la que decide
  el sentido cuando no hay ningún fin de carrera activo (`requirements.md` §4).
- **El parpadeo del LED necesita una pausa apagada antes de encenderse** (`LED_PAUSA_PARPADEO_MS`)
  — si se enciende de una tras `detenerMotor()` (que ya apaga el LED), la transición apagado→
  encendido pasa en microsegundos y el ojo humano no la distingue del "encendido fijo" que tenía
  el LED un instante antes por el movimiento. Bug real de la primera versión (sesión 008): el
  parpadeo estaba implementado pero nadie lo veía.
- **Todo case de `procesarComandoSerial()` debe terminar con `comando = 0;`.** Si no, el comando
  queda "pegado" y se reejecuta en cada iteración del `loop()` hasta que llegue otro. Bug real
  encontrado en hardware (sesión 006): los cases `'0'` (LED) y `'4'` (leer D0-D3) no lo hacían —
  heredado del `.ino` original — y quedaban repitiéndose solos. Ya corregido en los dos; si se
  agrega un case nuevo, no olvidar el `comando = 0;` al final.

## Seguridad

- El firmware maneja directamente relevos y disparo de TRIAC sobre carga de línea (motor 110VAC).
  Reglas duras pedidas por el usuario y ya implementadas en `porton.cpp` — cualquier cambio futuro
  debe preservarlas:
  1. Nunca ambos relevos activos a la vez (garantizado por construcción en `seleccionarSentido()`).
  2. El motor se detiene siempre antes de invertir sentido — nunca se conmuta el relevo con el
     motor energizado (`detenerMotor()` corta `TRIGGER` antes de liberar los relevos;
     `REVERSE_STOP_MS` de pausa antes de arrancar en el sentido contrario).
  3. Arranque siempre en estado seguro (`inicializarPines()`: relevos y `TRIGGER` en `HIGH`).
- El estado `ERROR` (atasco detectado) corta la potencia al entrar y **se sale solo con `D2`**
  (confirmado en hardware, sesión 006) — nunca automáticamente. Decisión deliberada: un atasco
  puede ser una obstrucción real, y reintentar por temporizador movería el motor de nuevo sin
  verificación humana (mismo criterio que UL 325 para fallas de obstrucción en portones
  automáticos). No agregar un reintento automático sin que el usuario lo pida explícitamente.
- **Cuidado al medir con osciloscopio de PC no aislado (p. ej. PicoScope 2208) sobre `ZCROSS`**,
  que está referenciado al lado de potencia (AC de red) a través del TRIAC. La pinza de tierra de
  la sonda puede crear un lazo de tierra entre la red eléctrica y el USB de la PC si toca un punto
  del circuito de potencia. Incidente en la sesión 006: tras medir así, la placa dejó de emitir
  cualquier salida por Serial (aunque seguía respondiendo a nivel de bootloader/USB); se
  recuperó sola al desconectar el osciloscopio, sin daño permanente aparente. Para medir `ZCROSS`
  con seguridad: sonda diferencial/aislada, o un transformador de aislación para el osciloscopio.

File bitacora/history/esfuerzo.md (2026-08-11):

# esfuerzo.md — Esfuerzo humano equivalente por sesión (append-only, OPCIONAL)

> Una fila por sesión. `horas-ingeniero` = rango que le tomaría a UN ingeniero senior hacer el
> mismo trabajo con calidad de producción (investigación + implementación + validación + docs).
> El detalle por funcionalidad va en `## Esfuerzo equivalente` del `sesion-{NNN}-{YYYY-MM-DD}.md`.
> Al cerrar: `printf '| N | YYYY-MM-DD | X-Y | funcionalidades |\n' >> bitacora/history/esfuerzo.md`

| Sesión | Fecha | horas-ingeniero | Funcionalidades clave |
| --- | --- | --- | --- |
| 1 | 2026-08-07 | 1.5-3 | Bootstrap stele + migracion firmware a PlatformIO |
| 2 | 2026-08-07 | 0.25-0.5 | Vinculo de repo remoto + primer commit/push |
| 3 | 2026-08-08 | 0.5-1 | Captura y verificacion del contrato de hardware |
| 4 | 2026-08-08 | 5.5-10 | Interlock relevos + maquina de estados + atasco por encoder + USB CDC |
| 5 | 2026-08-08 | 0.25-0.5 | Confirmaciones de diseno, sin cambios de codigo |
| 6 | 2026-08-08 | 6-10 | Validacion hardware + ENCA2 + rediseno control remoto D0/D2 |
| 7 | 2026-08-08 | 3.5-6 | Arranque suave del TRIAC por angulo de fase, sin confirmar en motor |
| 8 | 2026-08-11 | 7-12.5 | Contador de trayecto + LED + fix de posicion + calibracion TRIAC + radios apagadas |

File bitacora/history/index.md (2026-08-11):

# index.md — Índice de sesiones (append-only)

> Una fila por sesión. Al cerrar, agregar con Bash (sin leer el archivo completo):
> `printf '| N | YYYY-MM-DD | resumen | <session> |\n' >> bitacora/history/index.md`

| Sesión | Fecha | Resumen | Archivo |
| --- | --- | --- | --- |
| 1 | 2026-08-07 | Bootstrap de stele (layout agrupado) + firmware migrado a PlatformIO | sesion-001-2026-08-07.md |
| 2 | 2026-08-07 | Vinculado repo remoto (origin/main) + primer commit y push | sesion-002-2026-08-07.md |
| 3 | 2026-08-08 | Capturado contrato de hardware (pines ESP32-S3 + sistema de potencia) | sesion-003-2026-08-08.md |
| 4 | 2026-08-08 | Interlock de relevos + maquina de estados no bloqueante + timeout de encoder + USB CDC | sesion-004-2026-08-08.md |
| 5 | 2026-08-08 | Confirmaciones de diseno (control remoto, UART, idioma futuro) | sesion-005-2026-08-08.md |
| 6 | 2026-08-08 | Validacion en hardware real: control remoto D0/D2, ENCA2, atasco confirmado | sesion-006-2026-08-08.md |
| 7 | 2026-08-08 | Arranque suave del TRIAC (fase por ZCROSS), sin confirmar efecto en motor real | sesion-007-2026-08-08.md |
| 8 | 2026-08-11 | Contador de trayecto, LED, fix de rebote por inercia, TRIAC en potencia fija (release), radios apagadas | sesion-008-2026-08-11.md |

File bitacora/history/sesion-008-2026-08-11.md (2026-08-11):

# Sesión `008` — `2026-08-11`

Sesión larga: limpieza de diagnóstico, contador de trayecto, indicador LED, corrección de un bug
real de posición (rebote del imán por inercia), calibración empírica de la potencia del TRIAC en
el portón físico real hasta lograr un release funcional de punta a punta, apagado de radios,
revisión de código, README de portada y cierre de sesión con la vista puesta en un release.

## Qué se hizo

- **Limpieza del diagnóstico por Serial**: se sacaron `ENCA`/`ENCB` del print y de los contadores
  (no aportaban nada — `ENCA` siempre en 0 por el problema de hardware conocido, `ENCB` nunca se
  usó). Queda solo `ZCROSS`/`ENCA2`.
- **Contador de trayecto** (`requirements.md` §6): cuenta pulsos de `ENCA2` entre dos finales de
  carrera confirmados, sumando en el sentido del trayecto y restando en el contrario; se invalida
  en silencio si el trayecto se interrumpe (detenido parcial o `ERROR`). Pensado como insumo para
  una futura calibración de recorrido.
- **Indicador LED** (`requirements.md` §7): encendido fijo en movimiento, parpadeo al confirmar
  cada final de carrera. La primera versión del parpadeo no se notaba (transición imperceptible
  desde el "encendido por movimiento") — se corrigió agregando una pausa apagada visible antes del
  pulso.
- **Bug real encontrado por el usuario en el portón físico, corregido**: por inercia del motor, el
  imán de un fin de carrera puede rebasar el sensor al frenar, dejando "ningún fin de carrera
  activo" aunque el portón esté efectivamente en esa posición — el firmware volvía a intentar
  moverse hacia el mismo tope. Se agregó `ultimaLlegadaConfirmada` para decidir el sentido contra
  la última llegada real, no solo contra el estado actual de los switches (`requirements.md` §4).
- **Calibración empírica de la potencia del TRIAC en el portón real** (no solo el motor en banco):
  al 100% (disparo muy cerca del cruce por cero) el motor no se movía; se determinó que el TRIAC
  no enganchaba de forma confiable con esta carga inductiva tan cerca del cruce. Se probaron 90%,
  95%, se subió el pulso de gate de 200 a 500us, y se llegó a **85%** como primer nivel que mueve
  el portón de punta a punta sin las paradas falsas por "atasco" que daban los niveles más altos.
  Se agregó `POTENCIA_MOTOR_PCT` en `porton.h` como perilla ajustable (antes `POTENCIA_PRUEBA_PCT`,
  renombrada al pasar de "prueba" a comportamiento del release).
- **Decisión con el usuario: release en potencia fija, rampa de arranque suave pospuesta** — ver
  `design.md` → Decisiones estructurales, 2026-08-11.
- **Discusión de modo de bajo consumo (deep sleep)**: el usuario preguntó por reducir consumo/
  calor del ESP32-S3. Análisis conjunto: se descartó el deep sleep (el equipo está alimentado de
  red, no a batería — el ahorro no justifica perder el estado en RAM, la latencia de despertar, ni
  el Serial cortado justo en plena etapa de ajuste). Se implementó la alternativa de bajo riesgo:
  apagar Wi-Fi y Bluetooth explícitamente al arrancar (`apagarRadios()`), sin tocar el resto de la
  arquitectura.
- **Revisión de código**: se encontraron y corrigieron dos inconsistencias menores (dos lugares
  que invalidaban el contador de trayecto sin pasar por su mutex; `sentidoTrayecto` sin marcar
  `volatile` pese a compartirse con una interrupción).
- **README.md de portada** para el repositorio: descripción del proyecto, estado actual,
  limitaciones conocidas, estructura del repo, hardware, arranque de desarrollo.
- Documentación de bitácora actualizada: `requirements.md` (§4/§5 reescritas, §6/§7/§8 nuevas),
  `architecture.md` (patrones y flujos actualizados), `design.md` (nueva decisión estructural,
  glosario), `memory.md` (hallazgos técnicos: enganche del TRIAC cerca del cruce por cero, mutex
  del contador de trayecto, gotcha del parpadeo del LED, costo de la librería WiFi).

## Decisiones

- Ver `design.md` → Decisiones estructurales, 2026-08-11, y `requirements.md` §4/§5/§6/§7/§8.

## Archivos tocados

- `Firmware_Porton/include/porton.h`, `Firmware_Porton/src/porton.cpp` — todo lo descrito arriba.
- `README.md` — nuevo, en la raíz.
- `bitacora/requirements.md`, `bitacora/architecture.md`, `bitacora/design.md`,
  `bitacora/memory.md` — actualizados.

## Verificación

- `pio run` compila limpio en cada iteración de esta sesión (sin warnings propios).
- **Todo lo relativo al comportamiento del portón (contador de trayecto, LED, corrección de
  posición, niveles de potencia del TRIAC) se probó y confirmó en el portón físico real** por el
  usuario, no solo en banco — incluida la calibración de potencia que llevó al 85% final.
- El apagado de radios y las correcciones de la revisión de código **compilan pero no se
  verificaron en hardware todavía** — la placa no estaba conectada al cierre de esta sesión
  (`pio device list` no encontró nada). Queda pendiente que el usuario cargue esta última versión
  y confirme que el comportamiento no cambió.

## Notas para retomar

- **Cargar y probar la última versión** (apagado de radios + fixes de la revisión) en la placa
  real antes de confiar en ella para el release.
- Arranque/parada suaves (rampa real) quedan pospuestos — el 85% de potencia fija es la base para
  retomarlos más adelante, ya no valores sin probar.
- Sigue pendiente, sin tocar: la carpeta de KiCad renombrada (`PCB_Door_Controller/`, con
  archivos internos `PCB_Door_Controller_.*` que no coinciden con el nombre de la carpeta, y
  gerbers/producción desactualizados) — el usuario la sigue resolviendo por su cuenta.
- El usuario planea iniciar otro proyecto de sistemas embebidos — sin acción pendiente de este
  lado, solo queda anotado como contexto para la próxima vez que se hable de bootstrap de stele
  en un proyecto nuevo.

## Esfuerzo equivalente

| Funcionalidad | horas-ingeniero |
| --- | --- |
| Contador de trayecto + indicador LED (con la corrección del parpadeo) | 2-3 |
| Corrección del bug de rebote del imán por inercia (`ultimaLlegadaConfirmada`) | 1-2 |
| Calibración empírica de potencia del TRIAC en el portón real (varias rondas) | 2-4 |
| Análisis de bajo consumo + apagado de radios | 0.5-1 |
| Revisión de código + README + documentación de cierre | 1.5-2.5 |
| **Total** | **7-12.5** |

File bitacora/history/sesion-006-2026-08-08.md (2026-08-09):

# Sesión `006` — `2026-08-08`

Primera sesión con la placa física conectada (`COM8`). Validación completa en hardware real del
firmware, corrección de un bug de comandos, diagnóstico y reemplazo del encoder roto, y rediseño
del control remoto (D0/D2) con detención parcial y recuperación de fallas.

## Qué se hizo

- Ayudé al usuario a resolver un error de uso de PlatformIO (`pio run` corrido desde la raíz del
  proyecto en vez de `Firmware_Porton/`, donde vive `platformio.ini`).
- Cargado el firmware a la placa (`ESP32-S3-WROOM-1U-N8R8` real, confirmado por `esptool`: QFN56,
  8MB PSRAM). USB CDC nativo confirmado (VID:PID `303A:1001`).
- **Bug encontrado y corregido:** los comandos de prueba `'0'` (LED) y `'4'` (leer D0-D3) no
  limpiaban `comando` al terminar y quedaban reejecutándose solos en cada iteración del `loop()`
  — heredado del `.ino` original. Corregido en los dos.
- Agregado un diagnóstico temporal por Serial (`DEBUG_PULSOS` en `porton.h`, cada 1000ms) para
  contar pulsos de `ENCA`/`ENCB`/`ZCROSS`/`ENCA2`.
- **Validado en hardware:** apertura/cierre con un botón, finales de carrera, cambio de sentido,
  TRIAC/relevos a máxima potencia — todo funciona bien.
- **`ENCA`/`ENCB` resultaron tener un problema real de hardware** (resistencias de pull-up del
  circuito de entrada, encontrado por el usuario) — no generan pulsos. Se agregó `ENCA2`, un
  sensor Hall alternativo en `GPIO44` (UART0 RX, libre): confirmado en banco que da 0 pulsos con
  el motor quieto y pulsos reales con el motor girando. Se promovió a fuente real de detección de
  atasco, en paralelo con `ENCA` (por si se repara el hardware).
- **`ZCROSS` diagnosticado:** el usuario confirmó con un osciloscopio (PicoScope 2208) que la
  señal real es limpia (~120,8 Hz). El firmware contaba ~400-440/s por una interrupción `RISING`
  simple disparándose varias veces por rebote de umbral — se agregó antirrebote por software
  (`ZCROSS_DEBOUNCE_US`), que bajó el conteo a ~231-237/s. Sigue sin quedar exacto (queda como
  pendiente menor, no bloqueante — `ZCROSS` no dispara el TRIAC todavía).
- **Incidente de seguridad:** tras medir `ZCROSS` con el PicoScope (no aislado, referenciado a
  tierra por USB), la placa dejó de emitir cualquier salida por Serial. Se aisló con bisección
  que no era un problema de código; se recuperó sola al desconectar el osciloscopio. Documentado
  como gotcha de seguridad en `memory.md` (riesgo de lazo de tierra al medir señales referenciadas
  al lado de potencia).
- **Detección de atasco validada en hardware real:** al retirar el sensor Hall con el motor
  girando, el motor se detiene dentro del timeout configurado. El usuario ajustó
  `ENCODER_TIMEOUT_MS` a 2500ms tras ver la velocidad real del motor.
- **Rediseño del control remoto**, a pedido del usuario:
  - `D0` pasa a ser el único botón de control normal (antes era `D0`||`D1`).
  - Doble pulsación de `D0` dentro de 2s durante el movimiento: detiene y deja el portón a medio
    camino (apertura/cierre parcial), en vez de invertir sentido.
  - Botón dedicado para salir de `ERROR` — inicialmente asignado a `D1`, después movido a `D2` a
    pedido del usuario. Sin reintento automático tras un atasco (decisión deliberada, con
    justificación tipo UL 325 para fallas de obstrucción).
  - Las tres funciones (doble pulsación, reset de `ERROR`) se probaron y confirmaron en hardware
    real por el usuario.

## Decisiones

- Ver `design.md` → Decisiones estructurales, 2026-08-08 ("Validación en hardware real..."), y
  `requirements.md` §3/§4 para el detalle completo de la política de control remoto y de
  recuperación de `ERROR`.

## Archivos tocados

- `Firmware_Porton/platformio.ini`, `Firmware_Porton/include/porton.h`,
  `Firmware_Porton/src/porton.cpp`, `Firmware_Porton/src/main.cpp` — rediseño completo de la
  lógica de control remoto, detección de atasco (ENCA2), diagnóstico de pulsos.
- `bitacora/requirements.md` (§1, §3, §4 actualizadas), `bitacora/architecture.md` (patrones y
  brecha conocida), `bitacora/design.md` (nueva decisión estructural + glosario), `bitacora/
  memory.md` (gotchas de hardware: ENCA/ENCB, ENCA2, ZCROSS, incidente del osciloscopio, bug de
  `comando`).

## Verificación

- `pio run` compila limpio en cada iteración de esta sesión.
- **Todo lo descrito arriba se verificó en hardware real** (placa física, motor real), no solo en
  simulación/compilación — caso atípico para este proyecto hasta ahora. El propio usuario hizo las
  pruebas físicas (retirar el sensor con el motor girando, doble pulsación, atasco + reset).
- `ZCROSS` queda con un conteo de diagnóstico aproximado, no exacto — anotado como pendiente menor.

## Notas para retomar

- Sigue pendiente resolver la carpeta de KiCad renombrada (`PCB_Door_Controller/`, con archivos
  internos que no coinciden en nombre) — no se tocó en esta sesión tampoco.
- Board de PlatformIO (`esp32-s3-devkitc-1`) ya validado contra el módulo real, sin necesidad de
  ajustes — se puede quitar ese pendiente de `latest.md`.
- Próximo tema, a pedido del usuario: **control de potencia con el TRIAC** (la rampa de arranque
  suave con `ZCROSS`, pospuesta desde la sesión 004).
- El código de diagnóstico (`DEBUG_PULSOS`) sigue activo (`= 1`) — queda a criterio de una sesión
  futura apagarlo o dejarlo.

## Esfuerzo equivalente

| Funcionalidad | horas-ingeniero |
| --- | --- |
| Validación en hardware real (apertura/cierre, finales de carrera, interlock, atasco) | 1-2 |
| Diagnóstico y reemplazo del encoder (ENCA2, sensor Hall) | 2-3 |
| Diagnóstico de ZCROSS (antirrebote, incidente del osciloscopio) | 1-2 |
| Rediseño de control remoto (D0/D2, doble pulsación, recuperación de ERROR) | 2-3 |
| **Total** | **6-10** |

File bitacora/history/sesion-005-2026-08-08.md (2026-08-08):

# Sesión `005` — `2026-08-08`

Cierre del día: el usuario confirmó la lógica de control remoto, validó las dos preguntas
abiertas de hardware, y estableció una decisión de largo plazo sobre el idioma de la
documentación. Sin cambios de código.

## Qué se hizo

- **Lógica de control remoto confirmada:** el usuario corrigió su redacción original — es
  "abierta → cierra, cerrada → abre", tal como ya estaba implementado en `porton.cpp` desde la
  sesión 004. Se actualizó `requirements.md` §4 quitando la nota de "pendiente de confirmación".
- **Finales de carrera por polling:** confirmado que está bien dejarlos así por ahora (no hace
  falta pasarlos a interrupción todavía). Sin cambios de código.
- **UART de depuración confirmada:** `GPIO43` (TXD0) / `GPIO44` (RXD0), hacia un conector
  auxiliar en la placa. **No hay conflicto** con `TRIGGER` (`GPIO21`) — el comentario del `.ino`
  original que mencionaba IO20/21 para la UART estaba desactualizado. Documentado en `memory.md`.
- **Confirmado el rename externo de `PCB_puerta/`** detectado en la sesión 3: el usuario sí
  cambió el nombre de la carpeta. Durante esta sesión, en disco quedó consolidada una sola
  carpeta (`PCB_Door_Controller/`; la variante `PCB_Door_Controller_/` ya no está) — pero los
  archivos internos del proyecto KiCad siguen llamándose `PCB_Door_Controller_.*` (con guion
  bajo), distinto del nombre de la carpeta. Se deja sin commitear y sin tocar: falta confirmar
  con el usuario si ese nombre interno es intencional antes de versionar el rename.
- **Decisión de largo plazo:** cuando el proyecto se dé por terminado, toda la documentación se
  traduce a inglés (el destino es un pool de proyectos open-source de referencia del usuario).
  Mientras tanto sigue en español. Registrado en `design.md` → Norte / Restricciones.

## Decisiones

- Ver `design.md` → Restricciones (idioma de documentación) y `requirements.md` §4 (lógica de
  control remoto, ya confirmada, sin cambios de código).

## Archivos tocados

- `bitacora/requirements.md` — §4 actualizada (confirmación, ya no pendiente).
- `bitacora/memory.md` — nota sobre la UART de depuración (GPIO43/44) y descarte del conflicto
  con `GPIO21`.
- `bitacora/design.md` — Norte ampliado (pool open-source) y nueva restricción (idioma de
  documentación al finalizar).

## Verificación

- No aplica build/test — no se tocó código en esta sesión, solo documentación.

## Notas para retomar

- **Próxima sesión: trabajo con la placa física en mano.** Prioridad: `pio run -t upload` +
  validar en hardware real el interlock de relevos, el timeout de atasco del encoder, el USB CDC,
  y recién ahí confiar en el `board_build` actual (`esp32-s3-devkitc-1` sin ajustar a
  `ESP32-S3-WROOM-1U-N8R8`).
- Resolver cuál carpeta de KiCad es la definitiva (`PCB_Door_Controller` vs
  `PCB_Door_Controller_`) antes de volver a tocar el diseño de la placa en git.
- La traducción a inglés de la documentación **no se hace todavía** — es una tarea de cierre de
  proyecto, no de esta etapa.

## Esfuerzo equivalente

| Funcionalidad | horas-ingeniero |
| --- | --- |
| Revisión de confirmaciones + documentación de decisiones | 0.25-0.5 |
| **Total** | **0.25-0.5** |

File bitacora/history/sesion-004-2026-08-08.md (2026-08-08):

# Sesión `004` — `2026-08-08`

Primera implementación real de la lógica de control del portón: interlock de seguridad de
relevos, máquina de estados no bloqueante, detección de atasco por encoder, y USB CDC nativo.

## Qué se hizo

- El usuario respondió las 4 preguntas de diseño de la sesión 003 y agregó requisitos nuevos:
  TRIAC tratado como on/off (sin `ZCROSS` por ahora), encoder solo para detectar atasco (con
  timeouts por `#define`), estado `ERROR` como placeholder (recuperación a definir), finales de
  carrera confirmados como plantilla de pruebas (sin interrupción declarada), interlock de
  relevos ("nunca los dos activos"), motor debe detenerse ante cualquier cambio de sentido,
  lógica de control remoto basada en posición (solo `D0`/`D1` cableados), y habilitar el USB CDC
  nativo del ESP32-S3 en `platformio.ini`.
- Checkpoint de `handover.md` a `EN_PROGRESO` antes de tocar código (regla dura del módulo
  `software`), con el detalle del alcance y las trampas conocidas.
- `platformio.ini`: agregado `build_flags` (`ARDUINO_USB_MODE=1`, `ARDUINO_USB_CDC_ON_BOOT=1`).
- Reescritos `include/porton.h` y `src/porton.cpp`:
  - Nuevo enum `EstadoPuerta` (`DETENIDA`/`ABRIENDO`/`CERRANDO`/`ERROR`), reemplaza a
    `STOP`/`OPENING`/`CLOSING`/`ERROR`/`WAITING`.
  - `seleccionarSentido()` como único punto de escritura de los relevos (interlock estructural) y
    `detenerMotor()` (corta `TRIGGER` antes de liberar relevos).
  - Máquina de estados no bloqueante con `millis()`: `RELAY_SETTLE_MS`, `REVERSE_STOP_MS`,
    `ENCODER_TIMEOUT_MS`, `BOTON_DEBOUNCE_MS` como `#define` en `porton.h`.
  - Detección de atasco: interrupción en `ENCA` (`CHANGE`) que actualiza un timestamp; timeout
    sin pulsos con el TRIAC activo → `ERROR`.
  - Control remoto por flanco (`botonPresionado()`), no por nivel — reemplaza al `while()`
    bloqueante que esperaba a que se soltara el botón.
  - Lógica de sentido por posición real (fin de carrera), con default a "cerrar" en posición
    intermedia.
  - `procesarComandoSerial()` actualizado para reusar `seleccionarSentido()`/`detenerMotor()`.
- `pio run` — compila limpio (sin warnings en `porton.cpp`/`main.cpp`), Flash 7.9%, RAM 5.9%.
- Actualizados `requirements.md` (§1 revisado, §3 y §4 nuevas), `architecture.md` (reescrito:
  patrones nuevos, brecha conocida acotada a `ZCROSS`), `design.md` (nueva decisión estructural +
  glosario corregido), `memory.md` (gotchas actualizados a la nueva estructura).

## Decisiones

- Ver `design.md` → Decisiones estructurales, 2026-08-08, y `requirements.md` §3/§4 para el
  detalle completo (interlock, timeouts, política de control remoto).
- **Interpretación aplicada, pendiente de confirmar:** el mensaje del usuario sobre la lógica del
  control remoto decía literalmente "si el portón está abierto solo se puede abrir, si está
  cerrado solo se puede cerrar", que es lo opuesto de lo funcionalmente sensato (y de lo que ya
  hacía el firmware original). Se implementó la lógica intuitiva (abierta → cierra; cerrada →
  abre; intermedia → cierra por defecto) — **falta que el usuario la confirme antes de dar esto
  por cerrado.**

## Archivos tocados

- `Firmware_Porton/platformio.ini` — `build_flags` para USB CDC.
- `Firmware_Porton/include/porton.h` — reescrito.
- `Firmware_Porton/src/porton.cpp` — reescrito.
- `Firmware_Porton/src/main.cpp` — sin cambios (compatible con la nueva interfaz).
- `bitacora/requirements.md`, `bitacora/architecture.md`, `bitacora/design.md`,
  `bitacora/memory.md` — actualizados.

## Verificación

- `pio run` compila sin errores ni warnings propios (Flash 264941/3342336 bytes = 7.9%, RAM
  19280/327680 bytes = 5.9%).
- **No verificado:** nada de esto se probó contra hardware real (no hay placa conectada en este
  entorno) — ni el interlock de relevos, ni el timeout de atasco, ni la detección de flanco del
  botón, ni el USB CDC. Es revisión de lógica + compilación únicamente.
- La interpretación de la lógica abrir/cerrar (ver Decisiones) tampoco está confirmada por el
  usuario todavía.

## Notas para retomar

- **Confirmar con el usuario** la interpretación de la lógica de sentido del control remoto antes
  de considerar esto terminado — es un punto de seguridad real.
- El usuario dijo que definirá más adelante qué hacer al entrar/salir de `ERROR` — no hay
  recuperación implementada, solo corte de potencia.
- Cuando se retome el TRIAC con `ZCROSS`/rampa de arranque suave, revisar `architecture.md` →
  "Brecha conocida".
- Sigue pendiente la validación en hardware real (placa con módulo `ESP32-S3-WROOM-1U-N8R8`) y
  la resolución del rename externo de `PCB_puerta/` → `PCB_Door_Controller*` (ver `latest.md`).

## Esfuerzo equivalente

| Funcionalidad | horas-ingeniero |
| --- | --- |
| Rediseño de máquina de estados (interlock, no bloqueante, timeouts) | 2-4 |
| Detección de atasco por encoder (ISR + timeout) | 1-2 |
| Lógica de control remoto por posición (flanco + antirrebote) | 1-2 |
| Config. USB CDC + verificación de compilación | 0.5 |
| Actualización de documentación (specs/arquitectura/gotchas) | 1-1.5 |
| **Total** | **5.5-10** |

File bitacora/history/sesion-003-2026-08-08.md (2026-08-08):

# Sesión `003` — `2026-08-08`

Captura del contrato de hardware (sistema de potencia + pines ESP32-S3) que el usuario entregó
como referencia para el firmware que se va a escribir.

## Qué se hizo

- El usuario describió el sistema de potencia completo (motor 110VAC de fase partida con
  capacitor 33µF/400V, 2 relevos para sentido de giro, TRIAC para regular potencia, encoder de 2
  canales, 2 finales de carrera *reed switch*, receptor RF 433MHz) y entregó la tabla completa de
  los 13 pines del ESP32-S3 con tipo y polaridad de cada señal.
- Verificado ese contrato contra el firmware actual (`Firmware_Porton/`): las polaridades activas
  en LOW de relevos/TRIGGER y activas en alto de `D0`-`D3`/finales de carrera **ya coinciden** con
  el código existente; la polaridad del `LED` (activo en LOW) es dato nuevo, coincide por diseño
  con el estado inicial pero no estaba documentada.
- Detectada y documentada una brecha real: `ZCROSS`, `ENCA`/`ENCB` y `FC_OPEN`/`FC_CLOSE` están
  pensados como fuentes de **interrupción** en el contrato de hardware, pero el firmware actual no
  usa interrupciones en ninguno (finales de carrera por *polling*, `ZCROSS` sin usar, encoder sin
  leer).
- Escrito el contrato completo en `bitacora/temas/hardware-esp32-s3.md` (superaba el umbral de
  extracción de `requirements.md`), con resumen + link en `requirements.md` §2.
- Actualizado `memory.md` (gotchas de polaridad + la brecha de interrupciones), `design.md`
  (glosario: motor de fase partida, RELAY_OP/RELAY_CL vs TRIGGER, ENCA/ENCB) y `architecture.md`
  (sección "Brecha conocida" apuntando al mismo contrato, para cuando se toque esa parte del
  firmware).

## Decisiones

- Este contrato de hardware es la referencia autoritativa a partir de ahora: cualquier
  implementación de firmware que toque `ZCROSS`/`ENCA`/`ENCB`/`FC_OPEN`/`FC_CLOSE`/`TRIGGER`/
  relevos/`LED` debe ser consistente con `bitacora/temas/hardware-esp32-s3.md`, no con lo que el
  código actual asume por default.
- No se tocó ningún archivo de código en esta sesión (solo documentación) — no aplica la regla
  dura de checkpoint antes de editar código.

## Archivos tocados

- `bitacora/temas/hardware-esp32-s3.md` — nuevo, contrato completo.
- `bitacora/requirements.md` — nueva §2 (resumen + link al tema).
- `bitacora/memory.md` — gotchas de polaridad actualizados/ampliados (LED, brecha de
  interrupciones).
- `bitacora/design.md` — glosario ampliado.
- `bitacora/architecture.md` — nueva sección "Brecha conocida".

## Verificación

- Solo edición de documentación; no aplica build/test. Las polaridades citadas se contrastaron
  línea por línea contra `Firmware_Porton/include/porton.h` y `src/porton.cpp` (no se ejecutó
  nada, fue lectura de código).

## Notas para retomar

- Antes de escribir cualquier lógica nueva de firmware para `ZCROSS`/encoder/finales de carrera,
  hay preguntas de diseño abiertas que el agente le planteó al usuario en el chat de esta sesión
  (no repetidas aquí para no duplicar — si se responden, la decisión resultante va a
  `requirements.md` o a una nueva entrada en `design.md` → Decisiones estructurales, no solo a
  este registro).

## Esfuerzo equivalente

| Funcionalidad | horas-ingeniero |
| --- | --- |
| Captura y verificación del contrato de hardware (pines + sistema de potencia) | 0.5-1 |
| **Total** | **0.5-1** |

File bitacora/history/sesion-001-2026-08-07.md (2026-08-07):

# Sesión `001` — `2026-08-07`

Bootstrap del marco stele (layout `agrupado`) y reestructuración del firmware
`Firmware_Porton` de sketch `.ino` a proyecto PlatformIO.

## Qué se hizo

- Clonado el kit `stele` (`https://github.com/emezav/stele`) en `.stele/` (`git clone --depth 1`
  + `rm -rf .stele/.git`), siguiendo las instrucciones del propio repo.
- Ejecutado el ritual BOOTSTRAP (`.stele/SKILL.md`): layout `agrupado` (kit `.stele`, base
  `bitacora`, loader `CLAUDE.md`), módulo `software` activo, `persistencia = git`.
- Inicializado un repositorio git en la raíz del proyecto (no existía) — necesario para que
  `persistencia = git` sea válido; sin commits todavía.
- Reestructurado `Firmware_Porton/` como proyecto **PlatformIO** (entorno
  `esp32-s3-devkitc-1`, framework `arduino`): `platformio.ini`, `src/main.cpp`,
  `src/porton.cpp`, `include/porton.h`, `lib/`, `test/`. Se eliminó el `Firmware_Porton.ino`
  original (Arduino IDE); la lógica se separó en inicialización de pines, manejo de comandos
  Serial y máquina de estados de la puerta, sin cambiar el comportamiento.
- Agregado `.gitignore` en la raíz (build de PlatformIO, backups/caché de KiCad, artefactos de
  sesión de stele, archivos de SO).
- Escritos los documentos iniciales de `bitacora/`: `AGENTS.md`, `design.md`, `protocol.md`,
  `memory.md`, `requirements.md`, `architecture.md`, y el `stele.config.md` en la raíz.
- Generado el loader `CLAUDE.md` en la raíz.

## Decisiones

- **Layout `agrupado`** (`base = bitacora`) — decisión del usuario, tras preguntar: el proyecto
  ya organiza su contenido en carpetas por tipo (`Docs/`, `Firmware_Porton/`, `PCB_puerta/`), y
  agrupar los docs de stele en `bitacora/` sigue esa misma convención sin mezclar con esas
  carpetas. Registrado en `stele.config.md` → Rutas.
- **Board PlatformIO `esp32-s3-devkitc-1`** — el módulo real es `ESP32-S3-WROOM-1U-N8R8` (BOM de
  `PCB_puerta`); se usó la placa de referencia genérica del framework como aproximación, sin
  confirmar contra hardware real. Anotado como gotcha en `memory.md`.
- **Separación `main.cpp` / `porton.cpp` / `porton.h`** — a pedido del usuario, estructura típica
  de proyecto PlatformIO (init separado de la lógica de negocio), en vez de dejar todo en un
  único archivo como estaba en el `.ino`. Ver `architecture.md`.

## Archivos tocados

- `Firmware_Porton/Firmware_Porton.ino` — eliminado (reemplazado por la estructura PlatformIO).
- `Firmware_Porton/platformio.ini` — nuevo.
- `Firmware_Porton/include/porton.h` — nuevo (pines, enum `EstadoPuerta`, prototipos).
- `Firmware_Porton/src/porton.cpp` — nuevo (`inicializarPines`, `procesarComandoSerial`,
  `actualizarEstadoPuerta` — misma lógica que el `.ino` original).
- `Firmware_Porton/src/main.cpp` — nuevo (`setup`/`loop`, delega en `porton.cpp`).
- `Firmware_Porton/lib/README`, `Firmware_Porton/test/README` — nuevos (estándar PlatformIO).
- `.gitignore` — nuevo, en la raíz.
- `.stele/` — kit vendorizado (nuevo).
- `stele.config.md` — nuevo, en la raíz.
- `bitacora/AGENTS.md`, `bitacora/design.md`, `bitacora/protocol.md`, `bitacora/memory.md`,
  `bitacora/requirements.md`, `bitacora/architecture.md` — nuevos.
- `CLAUDE.md` — nuevo (loader de auto-arranque), en la raíz.

## Verificación

- `pio run` (desde `Firmware_Porton/`) — **compila correctamente** con el nuevo layout PlatformIO
  (Flash 8.3%, RAM 5.8%). Confirma que la separación en `main.cpp`/`porton.cpp`/`porton.h` no
  rompió el firmware.
- **No verificado:** `pio run -t upload` contra hardware real (no hay una placa conectada en este
  entorno), y el board `esp32-s3-devkitc-1` no se confirmó contra el módulo exacto
  (`ESP32-S3-WROOM-1U-N8R8`, 8MB flash / 8MB PSRAM octal) — puede requerir ajustar
  `board_build.*` en `platformio.ini` al probar en la placa real.
- No se hizo ningún commit todavía: el usuario decide cuándo persistir este estado inicial.

## Notas para retomar

- Antes de cargar a la placa real, confirmar el `board` de `platformio.ini` contra el datasheet
  exacto del módulo `ESP32-S3-WROOM-1U-N8R8` (flash/PSRAM) y ajustar si hace falta.
- El repositorio git está inicializado pero sin ningún commit — el primer commit (con este cierre
  de sesión incluido) queda pendiente de que el usuario lo autorice.
- `requirements.md`, `design.md` y `memory.md` tienen varias secciones marcadas `ADAPTAR`:
  contienen lo que se pudo inferir del código y del BOM, pero decisiones de negocio/normativas
  (§ Restricciones, § Modelo de datos, etc.) las tiene que completar el usuario.

## Esfuerzo equivalente

| Funcionalidad | horas-ingeniero |
| --- | --- |
| Bootstrap del marco de documentación (stele) | 0.5-1 |
| Reestructuración de firmware `.ino` → PlatformIO (sin cambio de comportamiento) | 1-2 |
| **Total** | **1.5-3** |

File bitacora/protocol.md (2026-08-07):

# protocol.md — Protocolo de documentación entre sesiones

> **Cómo** se documenta (formatos, convenciones de edición, topes de tamaño) para que ningún
> archivo de estado crezca sin límite y para minimizar tokens/roundtrips de cualquier agente.
> Los rituales condensados están en `.stele/SKILL.md`; el *por qué*, en `.stele/guide.md`.
> Los nombres de archivo abajo son los del manifiesto (`stele.config.md`, en la raíz).

## Principios

1. Los archivos de **estado** no crecen: se **sobrescriben** (formato fijo + tope).
2. El **historial** vive en archivos por sesión y **no se reabre** (se referencia por link).
3. Los **apéndices de una línea** usan `printf '...' >> archivo`, no `Read`+`Edit`.
4. Ninguna sección de un doc fuente-de-verdad supera **~150-200 líneas**; si crece, se extrae a
   un tema de `requirements.md` + link.
5. Nada de esto vive en memoria privada del agente; todo en el proyecto. **Tampoco los
   artefactos** —scripts de un solo uso, extracciones, volcados—: su hogar es
   `bitacora/artefactos/sesion-{NNN}/`, y esa regla vale por encima de cualquier default del
   harness (`.stele/SKILL.md` → Precedencia).
6. **Un hogar por dato** (mapa en `.stele/SKILL.md` y en `AGENTS.md`).

## Rutas: comando contra enlace

Dos clases, y no se resuelven igual:

- **Ruta de comando** (`printf '...' >> …`, `grep`, `git log --`): siempre **desde la raíz del
  proyecto**, incluyendo `bitacora/history/` delante del nombre del archivo (p. ej.
  `bitacora/history/index.md`).
- **Enlace Markdown clicable** (`[index.md](./index.md)`): relativo **al archivo que lo
  contiene**, que es como lo resuelve cualquier visor.

El `printf >>` del cierre es el que más vigilar: si la ruta está mal, **no da error** — crea el
archivo que falta y el bueno se queda sin la fila.

## Archivos y su rol

Ver `.stele/guide.md` → "Roles y fronteras". Aquí solo los **formatos**.

### `latest.md` — formato fijo, se SOBREESCRIBE (~100 líneas)

```markdown
# Estado actual
> Última sesión: Sesión N (YYYY-MM-DD) — ver sesion-{NNN}-{YYYY-MM-DD}.md
> Índice completo: index.md

## Dónde estamos
- (3-8 bullets del estado REAL, no histórico)
## Próximo paso inmediato
- (lo que haría la siguiente sesión; reemplaza, no acumula)
## Pendientes operativos
- Procesos en background / decisiones abiertas / trabajo sin persistir
## Referencias
- requirements.md §X — … / design.md § … / tema de requirements.md
```

Al cerrar: reescribir COMPLETO con `Write`. Nunca `Edit` para prepend/rename de "anterior".
En *Pendientes operativos* no anotes "push pendiente" por el commit que lleva este mismo cierre.

### `index.md` — tabla append-only

`| Sesión | Fecha | Resumen | Archivo |`. Al cerrar:
`printf '| N | YYYY-MM-DD | resumen | <session> |\n' >> bitacora/history/index.md`.

### `esfuerzo.md` — tabla append-only (OPCIONAL, feature `effort_log`)

`| Sesión | Fecha | horas-ingeniero | Funcionalidades clave |`. Estimar lo que le tomaría a UN
ingeniero senior el mismo trabajo con calidad de producción (investigación + implementación +
validación + docs), en rango. Detalle por funcionalidad en el `sesion-{NNN}-{YYYY-MM-DD}.md`.
Append: `printf '...' >> bitacora/history/esfuerzo.md`.

### `audit.md` — tabla append-only (OPCIONAL, feature `audit_log`)

`| Audit | Fecha | Sesiones | Alcance | Comprobadas | Hallazgos | Desenlace |`. Una fila por
auditoría (ritual AUDITAR). **Lo crea la primera auditoría, no el bootstrap.**

### `sesion-{NNN}-{YYYY-MM-DD}.md` — uno por sesión

Detalle completo: qué se hizo, decisiones, archivos tocados, verificación, notas para retomar,
y `## Esfuerzo equivalente`. `NNN` con padding a 3 dígitos. No se reabre; se lee con grep.

**No lleva su propio hash de commit.** El cierre viaja en el mismo commit que el trabajo, y un
commit no puede contener su propio hash. Para recuperarlo:
`git log --diff-filter=A -- bitacora/history/<archivo de sesión>`.

### `cartas.md` + `carta-{NNN}-{YYYY-MM-DD}.md` — la correspondencia (OPCIONAL, `correspondence_log`)

Misma forma que el historial: un índice (`cartas.md`), un archivo por carta
(`carta-{NNN}-{YYYY-MM-DD}.md`, en `bitacora/correspondencia/`) y su carpeta. Lo crea la primera
carta, no el bootstrap. Índice: `| # | Fecha | Dir | Corresponsal | Asunto | Desenlace |`, con
`Dir` = `->` sale · `<-` entra.

### `bitacora/artefactos/` — artefactos por sesión (se crea con el primero, no en bootstrap)

Un subdirectorio por sesión: `bitacora/artefactos/sesion-{NNN}/`. Dentro va lo que la sesión
produjo y **no es documentación**: scripts de un solo uso, extracciones, volcados intermedios.
Con `persistencia = git` no se versiona por defecto (ver `.gitignore`), salvo lo que el
`sesion-{NNN}-{YYYY-MM-DD}.md` marque como sostén de un cambio irreversible.

**El agente nunca limpia por su cuenta.** Borrar es decisión del usuario, siempre.

### `handover.md` — checkpoint de trabajo en curso (~50 líneas)

Estados: `SIN_TRABAJO_ACTIVO` | `EN_PROGRESO` | `COMPLETADO`. **Regla dura:** antes de la primera
edición de código, `EN_PROGRESO` con objetivo/alcance/verificación. Al cerrar, siempre refrescar
el puntero a la sesión que se cierra AHORA. Plantilla en `.stele/core/templates/handover.md`.

### `requirements.md` (+ temas)

Una sección por decisión o feature, **autocontenida**. Se lee con `grep` y por rango, nunca
entera.

**Umbral de extracción: ~50 líneas.** Por debajo, la decisión vive aquí. Por encima, se mueve a
`bitacora/temas/<TEMA>.md` y aquí queda un resumen de 2-3 líneas + link; si un tema supera
~600-800 líneas, se divide en sub-temas. `bitacora/temas/` se crea **cuando la primera decisión
cruce el umbral**, no en el scaffold.

### `memory.md`

Hogar único de gotchas de código (firmware y hardware). Se edita incrementalmente pero se
**cura** (se poda lo obsoleto). Una sección de subsistema que supera ~150-200 líneas se extrae a
un tema de `requirements.md`.

## Acuerdos de auditoría

Lo que el ritual AUDITAR señaló y el usuario decidió **no** cambiar. Se registra aquí para no
rediscutirlo en cada auditoría, y **siempre con umbral**.

| Fecha | Doc | Acuerdo | Umbral de revisión |
| --- | --- | --- | --- |

Un **tope de tamaño** de un rol no va aquí: es un **presupuesto** y su hogar es el manifiesto
(`stele.config.md`, sección Presupuestos, con el ritual `config`).

## Convenciones de texto (y dónde se escapan)

Este proyecto no impone una convención adicional de texto (más allá de escribir en español, como
el resto del código y la documentación). Si eso cambia, la regla vive en `AGENTS.md` →
Convenciones, y aquí solo se documenta **cómo se comprueba**.

## Checklist de inicio / cierre

Condensados en `.stele/SKILL.md` (rituales ABRIR / CERRAR). Este archivo es la referencia de
formato cuando haya dudas.

## Operaciones de bajo coste (preferir)

- Apéndice de fila → `printf '...' >> archivo`.
- Archivo pequeño de formato fijo → un `Write`.
- Buscar en archivo grande → `grep -n` + lectura por rango.
- Si vas a EDITAR, léelo con el tool `Read` (no `cat`/`sed`) o el `Edit` se bloquea.
- Volumen mecánico grande → delegar a un subagente.

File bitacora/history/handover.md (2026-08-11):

# handover.md

## Estado

SIN_TRABAJO_ACTIVO

## Última sesión cerrada

Sesión `8` (`2026-08-11`) — Contador de trayecto, indicador LED, corrección de un bug real de
posición (rebote del imán por inercia), TRIAC calibrado a potencia fija (85%) tras pruebas en el
portón real, radios Wi-Fi/Bluetooth apagadas, revisión de código, y README de portada. Ver
`sesion-008-2026-08-11.md` en `bitacora/history/`.
No hay trabajo a medias. Próximo paso: verificar en hardware la última carga, y crear el tag/
release en GitHub.

<!-- =========================================================================
     Cuando arranca un cambio interrumpible, SOBRESCRIBIR con la forma EN_PROGRESO:

## Estado
EN_PROGRESO

## Salto actual
Objetivo en una frase + decisiones ya tomadas que el siguiente agente debe respetar.

## Alcance permitido / No tocar
- permitido: <archivo/dir>
- no tocar: <archivo/dir fuera de alcance>

## Trampas de este salto
- Lo que sabes que puede salir mal en LO QUE VAS A HACER, no trampas generales del proyecto — esas
  viven en su hogar. Aquí van las que dispararían en las próximas horas.
- Es el sitio donde una advertencia llega a tiempo: un doc que se lee al arrancar informa; esto
  detiene. (Ver `.stele/SKILL.md` → la regla dura del checkpoint.)

## Estado intermedio
- Qué quedó a medias (p. ej. "X hecho, Y pendiente -> inconsistente hasta Y").
- Qué está sin persistir (sin commitear, si `persistencia = git`).

## Pendiente inmediato (en orden)
- Paso 1 concreto para retomar...

## Si fui interrumpido
Retomar desde: ...   No repetir: ...
========================================================================= -->

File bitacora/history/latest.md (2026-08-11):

# Estado actual

> Última sesión: Sesión `8` (`2026-08-11`) — ver `sesion-008-2026-08-11.md`
> Índice completo de sesiones: [index.md](./index.md)
> Protocolo de documentación: [protocol.md](../protocol.md)

## Dónde estamos

- **El portón funciona de punta a punta en hardware real**, validado por el usuario: abrir/
  cerrar con un botón, inversión de sentido, detenido parcial, detección de atasco con reset
  manual, indicador LED, y el TRIAC a potencia fija calibrada (85%, ver `requirements.md` §5).
- Corregido un bug real de posición (rebote del imán del fin de carrera por inercia del motor) —
  ver `ultimaLlegadaConfirmada`, `requirements.md` §4.
- Agregado un contador de trayecto (`requirements.md` §6) como insumo para una futura calibración
  de recorrido, y apagadas las radios Wi-Fi/Bluetooth (`requirements.md` §8, sin deep sleep — el
  equipo va a red, no a batería).
- Escrito el primer `README.md` de portada del repositorio, con la vista puesta en un release.
- **Pendiente de verificar en hardware:** los últimos cambios de esta sesión (apagado de radios,
  dos fixes menores de la revisión de código) compilan pero no se cargaron a la placa — no estaba
  conectada al cierre.

## Próximo paso inmediato

- Cargar la última versión a la placa real y confirmar que el comportamiento no cambió (apagado
  de radios + fixes de revisión).
- Crear el tag/release en GitHub para esta versión (pedido explícito del usuario, en curso).

## Pendientes operativos

- Verificar en hardware real la última carga (ver arriba).
- Retomar arranque/parada suaves (rampa real del TRIAC) en una sesión futura — el 85% de potencia
  fija ya es una base fiable para partir, en vez de valores sin probar.
- Sigue sin resolver la carpeta de KiCad renombrada (`PCB_Door_Controller/`) — nombre de archivos
  internos que no coincide con la carpeta, gerbers/producción desactualizados. El usuario la
  sigue trabajando por su cuenta; no se toca desde acá.
- El usuario va a iniciar otro proyecto de sistemas embebidos — sin acción pendiente en este
  proyecto, queda anotado como contexto.

## Referencias

- `requirements.md` §4/§5/§6/§7/§8 — posición inferida, TRIAC en potencia fija, contador de
  trayecto, LED, radios apagadas.
- `design.md` → Decisiones estructurales, 2026-08-11.
- `memory.md` — hallazgos técnicos de esta sesión (enganche del TRIAC, mutex del contador, etc.).
- `README.md` (raíz) — portada del repositorio.

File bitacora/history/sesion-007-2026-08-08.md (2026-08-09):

# Sesión `007` — `2026-08-08`

Arranque suave del TRIAC (disparo por ángulo de fase, sincronizado a `ZCROSS`). Planeado con el
usuario antes de tocar código (plan mode), implementado, subido a la placa — pero sin confirmar
todavía que produzca un arranque perceptiblemente más suave en el motor real.

## Qué se hizo

- Ayudé al usuario con un problema de uso de `pio run` (corrido desde la raíz en vez de
  `Firmware_Porton/`).
- El usuario pidió arranque y parada suaves del TRIAC (el portón golpea fuerte al cerrar) y pidió
  explícitamente un plan antes de escribir código. Usé el modo de planificación: hice dos
  preguntas de diseño (cómo detectar cuándo frenar sin posición absoluta; requisitos del pulso de
  disparo del TRIAC) y escribí un plan que el usuario aprobó.
- El usuario acotó el alcance en la conversación de planificación: **solo arranque suave esta
  ronda**, para validar el mecanismo de disparo por fase; la parada suave con calibración de
  recorrido por conteo de pulsos queda para una sesión futura, a especificar por el usuario.
  Confirmó el TRIAC (`BT138-800`) y el pulso de gate (200us, ya usado en proyectos anteriores).
- Implementado en `Firmware_Porton/include/porton.h` / `src/porton.cpp`:
  - `ZCROSS` pasa de interrupción solo-diagnóstico a interrupción real: arma un `esp_timer`
    (`timerDisparo`) con el retardo de fase actual; su callback pulsa `TRIGGER` y arma un segundo
    `esp_timer` (`timerPulso`) que lo suelta tras `PULSO_TRIAC_US`.
  - Rampa de arranque (`actualizarRampa()`, llamada desde `manejarMovimiento()`): interpola el
    retardo de disparo entre `DISPARO_US_MIN` (potencia baja) y `DISPARO_US_MAX` (potencia de
    crucero) durante `RAMPA_ARRANQUE_MS`.
  - `detenerMotor()` cancela el temporizador de disparo pendiente (`esp_timer_stop`) antes de
    forzar `TRIGGER` a `HIGH`, para que no quede un pulso de gate programado tras decidir parar.
  - Intenté usar `ESP_TIMER_ISR` como método de despacho (menor jitter) — no compiló, esta build
    de Arduino-ESP32 no lo tiene habilitado. Se usa el despacho por defecto (`ESP_TIMER_TASK`).
  - Efecto lateral bueno: subir `ZCROSS_DEBOUNCE_US` de 1000 a 3000us (necesario para que
    `isrZcross()` no arme el disparo dos veces por el mismo cruce) dejó el conteo de diagnóstico
    de `ZCROSS` en 120/s exactos — coincide con los ~120,8 Hz reales medidos en la sesión 006.
- Compilado, subido a `COM8`, verificado que el firmware sigue arrancando y reportando con
  normalidad (sin crash, diagnóstico de pulsos funcionando).
- **El usuario probó un movimiento real y no notó ninguna diferencia** respecto del arranque
  anterior a máxima potencia — percepción de que arranca "al 100%". Le pedí que revise con el
  osciloscopio (relación `ZCROSS`↔`TRIGGER`, si el retardo varía durante la rampa) antes de seguir
  ajustando a ciegas. El usuario va a hacer esa prueba en otra sesión.

## Decisiones

- Ver `design.md` → Decisiones estructurales, 2026-08-08 ("Arranque suave del TRIAC..."), y
  `requirements.md` §5 para el detalle completo del alcance y los parámetros.

## Archivos tocados

- `Firmware_Porton/include/porton.h` — constantes de disparo por fase y rampa.
- `Firmware_Porton/src/porton.cpp` — ISR real de `ZCROSS`, temporizadores del TRIAC, rampa de
  arranque, cancelación en `detenerMotor()`.
- `bitacora/requirements.md` (§5 nueva), `bitacora/architecture.md` (patrones + brecha
  actualizada), `bitacora/design.md` (nueva decisión estructural), `bitacora/memory.md`
  (gotchas técnicos + hipótesis abiertas).
- Plan de esta sesión: `C:\Users\Yabo\.claude\plans\nifty-cooking-stardust.md` (local, fuera del
  repo — no es parte de la bitácora, es la herramienta de planificación de la sesión).

## Verificación

- `pio run` compila limpio (sin warnings propios).
- Subido a `COM8` y verificado por Serial que arranca sin crash y el diagnóstico de pulsos sigue
  funcionando (`ZCROSS` ahora en 120/s exactos).
- **No verificado:** que el arranque suave produzca una diferencia real en el motor. El usuario
  probó un movimiento real y no notó cambio — queda como pendiente explícito, no como fallo
  confirmado ni como éxito confirmado. Sin datos de osciloscopio todavía.

## Notas para retomar

- **Antes de seguir tocando parámetros de la rampa**, conseguir el dato del osciloscopio
  (`ZCROSS` vs `TRIGGER` durante un movimiento real): confirma si el retardo de disparo
  efectivamente varía, lo cual separa "bug en el mecanismo" de "el motor de inducción no responde
  mucho a corte de fase en velocidad" (ver memory.md, dos hipótesis abiertas).
- Si el retardo NO varía en el osciloscopio: revisar primero si `esp_timer_start_once`/
  `esp_timer_stop` llamados desde `isrZcross()` (ISR de GPIO real) están funcionando de verdad en
  esta build — es el punto menos verificado de esta sesión.
- Parada suave y calibración de recorrido siguen sin diseñarse — el usuario dijo que las
  especifica más adelante.
- Sigue pendiente, sin tocar: la carpeta de KiCad renombrada (`PCB_Door_Controller/`).

## Esfuerzo equivalente

| Funcionalidad | horas-ingeniero |
| --- | --- |
| Planificación (plan mode, preguntas de diseño, plan escrito y aprobado) | 0.5-1 |
| Implementación del disparo por fase + rampa de arranque | 2-3 |
| Depuración de compilación (`ESP_TIMER_ISR`) + verificación en hardware | 0.5-1 |
| Documentación | 0.5-1 |
| **Total** | **3.5-6** |

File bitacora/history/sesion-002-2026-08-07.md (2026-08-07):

# Sesión `002` — `2026-08-07`

Vinculación del proyecto al repositorio remoto del usuario y primer commit + push.

## Qué se hizo

- El usuario confirmó que la tarjeta de trabajo es el módulo **ESP32-S3** y que el repositorio a
  usar es `https://github.com/yabo104/Electric_Door_With_ESP32_S3.git`.
- Verificado con `git ls-remote` que el repositorio existe y está **vacío** (sin ramas ni
  commits) antes de tocar nada.
- Configurado `git remote add origin` con esa URL y fijada la rama inicial en `main` (en vez del
  `master` por defecto de `git init`).
- Confirmado con el usuario (pregunta explícita) qué hacer con el trabajo pendiente de commitear
  de la Sesión 1; eligió "commit y push ahora".
- Revisado el staging antes de commitear: sin archivos de secretos/credenciales, `.gitignore`
  excluyendo correctamente `.pio/`, backups y caché de KiCad (~7.0 MB efectivos de 75 archivos).
- Hecho el primer commit (`bbcb7d3`, root-commit) con todo el estado de la Sesión 1 (stele +
  firmware PlatformIO + diseño PCB + datasheets) y `git push -u origin main`.

## Decisiones

- **Rama por defecto `main`**, no `master` — para que coincida con la convención actual de
  GitHub y con la rama que ya sigue el remoto vacío del usuario.
- **Commit único para todo el estado inicial** (stele + firmware + PCB + docs) en vez de varios
  commits separados, porque nada de eso estaba versionado todavía y todo pertenece al mismo punto
  de partida del proyecto.

## Archivos tocados

- (config de git, sin archivos de proyecto) `git remote add origin`, `git symbolic-ref HEAD
  refs/heads/main`.
- Commit `bbcb7d3` — todo el árbol de trabajo de la Sesión 1 (75 archivos).

## Verificación

- `git ls-remote` confirmó el repo remoto vacío antes de pushear (sin riesgo de sobreescribir
  historial ajeno).
- `git push -u origin main` — reportó `* [new branch] main -> main` y dejó `main` trackeando
  `origin/main`.
- No se repitió `pio run`: no hubo cambios de código en esta sesión, solo control de versiones.

## Notas para retomar

- El repo remoto (`origin/main`) ya tiene el estado completo de la Sesión 1 + este cierre.
- Sigue pendiente confirmar el `board` exacto de PlatformIO contra el módulo real
  (`ESP32-S3-WROOM-1U-N8R8`) al probar en hardware, y completar las secciones `ADAPTAR` de
  `design.md`/`requirements.md`.

## Esfuerzo equivalente

| Funcionalidad | horas-ingeniero |
| --- | --- |
| Vincular remoto + primer commit/push (con verificación de repo vacío y de secretos) | 0.25-0.5 |
| **Total** | **0.25-0.5** |

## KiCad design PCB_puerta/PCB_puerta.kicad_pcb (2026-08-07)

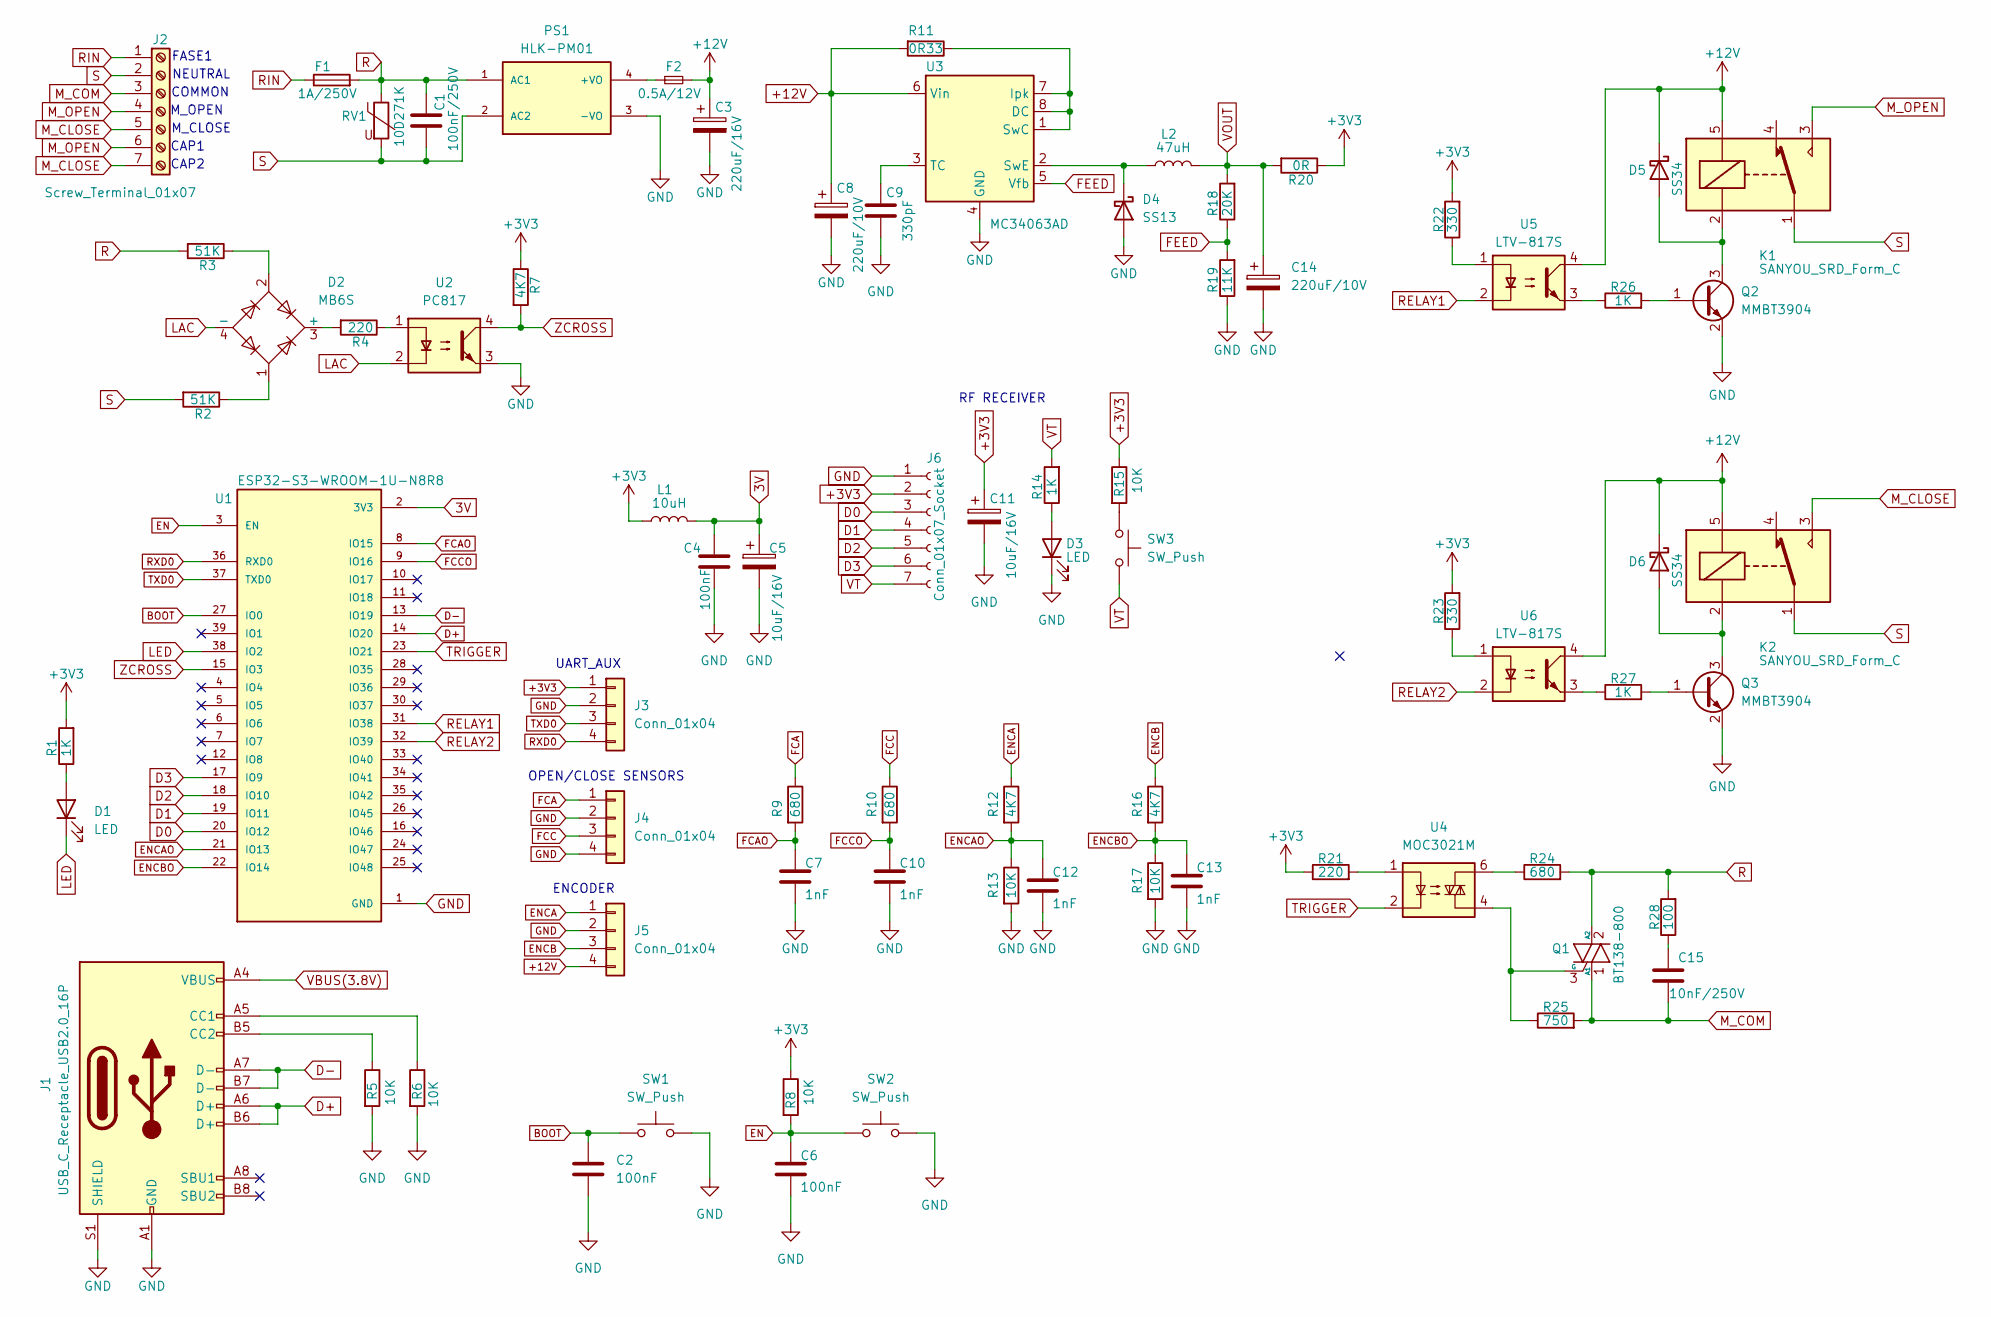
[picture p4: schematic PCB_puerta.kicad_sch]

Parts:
C1: 100nF/250V; C_Disc_D10.5mm_W5.0mm_P7.50mm
C2, C4, C6: 100nF; C_0603_1608Metric
C3: 220uF/16V; CP_Elec_6.3x7.7
C5, C11: 10uF/16V; CP_EIA-3216-10_Kemet-I
C7, C10, C12, C13: 1nF; C_0603_1608Metric
C8, C14: 220uF/10V; CP_Elec_6.3x7.7
C9: 330pF; C_0603_1608Metric
C15: 10nF/250V; C_Disc_D7.5mm_W5.0mm_P7.50mm
D1, D3: LED; LED_0805_2012Metric
D2: MB6S; TO-269AA
D4: SS13; D_SMA
D5, D6: SS34; D_SMA
F1: 1A/250V; Fuseholder_Clip-5x20mm_Littelfuse_445-030_Inline_P20.50x5.2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
F2: 0.5A/12V; Fuse_0805_2012Metric
J1: USB_C_Receptacle_USB2.0_16P; USB_C_Receptacle_GCT_USB4105-xx-A_16P_TopMnt_Horizontal
J2: Screw_Terminal_01x07; TerminalBlock_MaiXu_MX126-5.0-07P_1x07_P5.00mm
J3, J4: Conn_01x04; JST_PH_B4B-PH-K_1x04_P2.00mm_Vertical
J5: Conn_01x04; Molex_KK-254_AE-6410-04A_1x04_P2.54mm_Vertical
J6: Conn_01x07_Socket; PinHeader_1x07_P2.54mm_Vertical
K1, K2: SANYOU_SRD_Form_C; Relay_SPDT_SANYOU_SRD_Series_Form_C
L1: 10uH; L_0603_1608Metric
L2: 47uH; L_Changjiang_FXL0624
PS1: HLK-PM01; CONV_HLK-PM01
Q1: BT138-800; TO-220-3_Vertical
Q2, Q3: MMBT3904; SOT-23
R1, R14: 1K; R_0603_1608Metric
R2, R3: 51K; R_0603_1608Metric
R4: 220; R_0603_1608Metric
R5, R6, R8, R13, R15, R17: 10K; R_0603_1608Metric
R7, R12, R16: 4K7; R_0603_1608Metric
R9, R10: 680; R_0603_1608Metric
R11: 0R33; R_0603_1608Metric
R18: 20K; R_0603_1608Metric
R19: 11K; R_0603_1608Metric
R20: 0R; R_0603_1608Metric
R21: 220; R_0603_1608Metric_Pad0.98x0.95mm_HandSolder
R22, R23: 330; R_0603_1608Metric_Pad0.98x0.95mm_HandSolder
R24: 680; R_0603_1608Metric_Pad0.98x0.95mm_HandSolder
R25: 750; R_0603_1608Metric_Pad0.98x0.95mm_HandSolder
R26, R27: 1K; R_0603_1608Metric_Pad0.98x0.95mm_HandSolder
R28: 100; R_Axial_DIN0414_L11.9mm_D4.5mm_P15.24mm_Horizontal
RV1: 10D271K; RV_Disc_D12mm_W3.9mm_P7.5mm
SW1, SW2, SW3: SW_Push; SW_Tactile_SPST_NO_Straight_CK_PTS636Sx25SMTRLFS
U1: ESP32-S3-WROOM-1U-N8R8; ESP32-S3-WROOM-1; PARTREV v1.1
U2: PC817; SMDIP-4_W9.53mm
U3: MC34063AD; SOIC-8_3.9x4.9mm_P1.27mm
U4: MOC3021M; DIP-6_W7.62mm_LongPads
U5, U6: LTV-817S; SMDIP-4_W9.53mm

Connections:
3V: C4.1, C5.1, L1.2, U1.2 (3V3)
+3V3: C11.1, J3.1, J6.2, L1.1, R1.2, R7.1, R8.1, R15.1, R20.1, R21.1, R22.2, R23.2
+12V: C3.1, C8.1, D5.1 (K), D6.1 (K), F2.2, J5.4, K1.5, K2.5, R11.2, U3.6 (Vin), U5.4, U6.4
BOOT: C2.1, SW1.1, U1.27 (IO0)
D0: J6.3, U1.20 (IO12)
D1: J6.4, U1.19 (IO11)
D2: J6.5, U1.18 (IO10)
D3: J6.6, U1.17 (IO9)
D+: J1.A6 (D+), J1.B6 (D+), U1.14 (IO20)
D-: J1.A7 (D-), J1.B7 (D-), U1.13 (IO19)
EN: C6.1, R8.2, SW2.1, U1.3 (EN)
ENCA: J5.1, R12.1
ENCAO: C12.1, R12.2, R13.1, U1.21 (IO13)
ENCB: J5.3, R16.1
ENCBO: C13.1, R16.2, R17.1, U1.22 (IO14)
FCA: J4.1, R9.1
FCAO: C7.1, R9.2, U1.8 (IO15)
FCC: J4.3, R10.1
FCCO: C10.1, R10.2, U1.9 (IO16)
FEED: R18.1, R19.2, U3.5 (Vfb)
GND: C2.2, C3.2, C4.2, C5.2, C6.2, C7.2, C8.2, C9.2, C10.2, C11.2, C12.2, C13.2, C14.2, D3.1 (K), D4.2 (A), J1.A1 (GND), J1.A12 (GND), J1.B1 (GND), J1.B12 (GND), J1.S1 (SHIELD), J3.2, J4.2, J4.4, J5.2, J6.1, PS1.3 (-VO), Q2.2 (E), Q3.2 (E), R5.2, R6.2, R13.2, R17.2, R19.1, SW1.2, SW2.2, U1.1 (GND), U1.40 (GND), U1.41_1 (GND), U1.41_2 (GND), U1.41_3 (GND), U1.41_4 (GND), U1.41_5 (GND), U1.41_6 (GND), U1.41_7 (GND), U1.41_8 (GND), U1.41_9 (GND), U2.3, U3.4 (GND)
LAC: D2.4 (-), U2.2
LED: D1.1 (K), U1.38 (IO2)
M_CLOSE: J2.5, J2.7, K2.3
M_COM: C15.2, J2.3, Q1.1 (A1), R25.2
M_OPEN: J2.4, J2.6, K1.3
unnamed: C15.1, R28.1
unnamed: D1.2 (A), R1.1
unnamed: D2.3 (+), R4.2
unnamed: D2.1, R2.1
unnamed: D2.2, R3.1
unnamed: D3.2 (A), R14.1
unnamed: D4.1 (K), L2.1, U3.2 (SwE)
unnamed: D5.2 (A), K1.2, Q2.3 (C)
unnamed: D6.2 (A), K2.2, Q3.3 (C)
unnamed: J1.A5 (CC1), R6.1
unnamed: J1.B5 (CC2), R5.1
unnamed: F2.1, PS1.4 (+VO)
unnamed: Q1.3 (G), R25.1, U4.4
unnamed: Q2.1 (B), R26.2
unnamed: Q3.1 (B), R27.2
unnamed: R4.1, U2.1
unnamed: R15.2, SW3.1
unnamed: R21.2, U4.1
unnamed: R22.1, U5.1
unnamed: R23.1, U6.1
unnamed: R24.1, U4.6
unnamed: R26.1, U5.3
unnamed: R27.1, U6.3
unnamed: R11.1, U3.1 (SwC), U3.7 (Ipk), U3.8 (DC)
unnamed: C9.1, U3.3 (TC)
R: C1.1, F1.2, PS1.1 (AC1), Q1.2 (A2), R3.2, R24.2, R28.2, RV1.1
RELAY1: U1.31 (IO38), U5.2
RELAY2: U1.32 (IO39), U6.2
RIN: F1.1, J2.1
RXD0: J3.4, U1.36 (RXD0)
S: C1.2, J2.2, K1.1, K2.1, PS1.2 (AC2), R2.2, RV1.2
TRIGGER: U1.23 (IO21), U4.2
TXD0: J3.3, U1.37 (TXD0)
VBUS(3.8V): J1.A4 (VBUS), J1.A9 (VBUS), J1.B4 (VBUS), J1.B9 (VBUS)
VOUT: C14.1, L2.2, R18.2, R20.2
VT: J6.7, R14.2, SW3.2
ZCROSS: R7.2, U1.15 (IO3), U2.4

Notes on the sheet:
OPEN/CLOSE SENSORS
RF RECEIVER
CAP2
M_CLOSE
FASE1
CAP1
M_OPEN
ENCODER
UART_AUX
NEUTRAL
COMMON

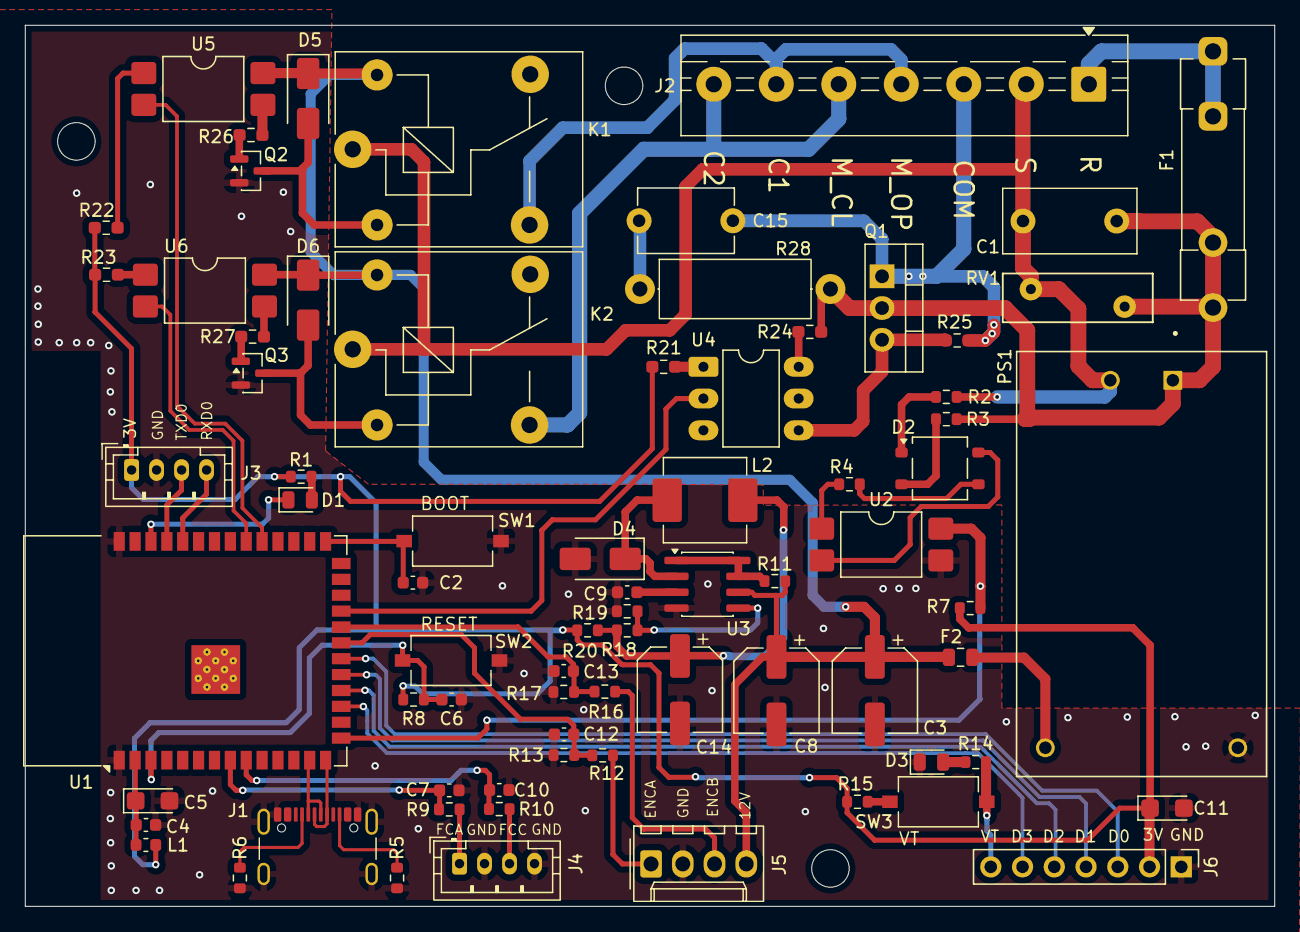
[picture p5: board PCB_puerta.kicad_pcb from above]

Board: 2 copper layers, 99.9 x 70.5 mm, 75 parts (0 on the bottom side), 63 nets.

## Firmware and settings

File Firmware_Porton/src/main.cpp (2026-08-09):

#include <Arduino.h>
#include "porton.h"

void setup() {
  inicializarPines();

  Serial.begin(115200);
  delay(500);

  Serial.println("Inicializacion Completa");
}

void loop() {
  if (Serial.available()) {
    comando = Serial.read();
  }

  procesarComandoSerial();
  actualizarEstadoPuerta();

#if DEBUG_PULSOS
  mostrarPulsos();
#endif
}

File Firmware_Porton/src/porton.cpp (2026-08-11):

#include "porton.h"
#include "esp_timer.h"
#include <WiFi.h>

char comando = 0;

char doorStd     = DETENIDA;
char doorLastStd = DETENIDA;

/* --- Estado interno de la maquina (no expuesto en el header: uso exclusivo de este archivo) --- */

static volatile unsigned long ultimoPulsoEncoderISR = 0;  // se actualiza desde la interrupcion
static unsigned long tInicioSentido = 0;   // cuando se activo el relevo del sentido actual
static bool triacActivo = false;           // si ya se habilito el TRIAC en el movimiento actual
static char sentidoPendiente = 0;          // ABRIENDO/CERRANDO si hay una reversa en espera
static unsigned long tEntradaDetenida = 0; // cuando se entro a DETENIDA (para REVERSE_STOP_MS)
static bool estadoD0Anterior = false;      // para detectar flanco de subida de D0
static unsigned long tUltimoD0 = 0;        // antirrebote de D0
static bool estadoResetAnterior = false;   // para detectar flanco de subida del boton de reset
static unsigned long tUltimoReset = 0;     // antirrebote del boton de reset
static unsigned long tUltimaPulsacionMovimiento = 0;  // para detectar doble pulsacion de D0
static char ultimaLlegadaConfirmada = 0;   // ultimo ABRIENDO/CERRANDO que llego a su fin de
                                            // carrera de verdad (0 = ninguna todavia)

/* --- Contador de trayecto (ENCA2): solo valido entre dos finales de carrera confirmados --- */

static portMUX_TYPE muxTrayecto = portMUX_INITIALIZER_UNLOCKED;
static volatile long contadorTrayecto = 0;   // suma en el sentido del trayecto, resta al reves
static volatile bool trayectoActivo = false; // false = conteo invalido (origen no confirmado)
static volatile char sentidoTrayecto = 0;    // sentido con el que arranco el trayecto actual

/* --- Parpadeo no bloqueante del LED al detectar un fin de carrera --- */
/* Fases: 0 = inactivo. 1 = pausa apagado (para que se note el flanco: el LED ya viene encendido
   fijo desde que el motor se movia, si se prendiera de nuevo sin una pausa visible no se
   distingue del "encendido por movimiento"). 2 = parpadeo encendido. */

static uint8_t faseParpadeoLed = 0;
static unsigned long tFaseParpadeoLed = 0;

/* --- Disparo del TRIAC por angulo de fase, sincronizado a ZCROSS --- */

static portMUX_TYPE muxRampa = portMUX_INITIALIZER_UNLOCKED;
static volatile uint32_t delayDisparoActualUS = DISPARO_US_MAX;  // leido por isrZcross()
static unsigned long tInicioRampa = 0;      // cuando arranco el TRIAC en este movimiento
static volatile unsigned long tUltimoZcrossUS = 0;  // antirrebote de ZCROSS (real, no solo diag.)
static esp_timer_handle_t timerDisparo = NULL;  // dispara el gate tras el retardo de fase
static esp_timer_handle_t timerPulso = NULL;    // apaga el pulso de gate tras PULSO_TRIAC_US

// Se llama solo desde manejarMovimiento(), mientras triacActivo. Interpola el retardo de disparo
// entre DISPARO_US_MIN (al arrancar) y DISPARO_US_MAX (potencia de crucero) durante
// RAMPA_ARRANQUE_MS; despues queda fijo en DISPARO_US_MAX. No bloqueante.
static void actualizarRampa() {
  unsigned long elapsed = millis() - tInicioRampa;
  uint32_t delay;
  if (elapsed >= RAMPA_ARRANQUE_MS) {
    delay = DISPARO_US_MAX;
  } else {
    delay = DISPARO_US_MIN -
            (uint32_t)(((uint64_t)(DISPARO_US_MIN - DISPARO_US_MAX) * elapsed) / RAMPA_ARRANQUE_MS);
  }
  portENTER_CRITICAL(&muxRampa);
  delayDisparoActualUS = delay;
  portEXIT_CRITICAL(&muxRampa);
}

// Callbacks de los esp_timer (corren en la tarea de esp_timer, no en una ISR real -- ver la nota
// en inicializarPines()). Se mantienen minimos igual: un digitalWrite y, en el primero, programar
// el segundo.
static void IRAM_ATTR onDisparoTriac(void* arg) {
  digitalWrite(TRIGGER, LOW);
  esp_timer_start_once(timerPulso, PULSO_TRIAC_US);
}

static void IRAM_ATTR onFinPulsoTriac(void* arg) {
  digitalWrite(TRIGGER, HIGH);
}

/* --- Interrupcion del encoder: solo registra que hubo un pulso, no cuenta ni decodifica --- */

#if DEBUG_PULSOS
static portMUX_TYPE muxPulsos = portMUX_INITIALIZER_UNLOCKED;
static volatile unsigned long pulsosZcross = 0;
static volatile unsigned long pulsosEncA2 = 0;
static unsigned long tUltimoReportePulsos = 0;
#endif

static void IRAM_ATTR isrEncoder() {
  ultimoPulsoEncoderISR = millis();
}

// ENCA2: sensor Hall en GPIO44 (ver porton.h), alternativa a ENCA mientras ENCA/ENCB tengan el
// problema de pull-up conocido en hardware. Confirmado en banco (sesion 006): 0 pulsos con el
// motor quieto, pulsos reales con el motor girando. Alimenta la MISMA deteccion de atasco que
// ENCA (ultimoPulsoEncoderISR) -- cualquiera de los dos canales que pulse resetea el timeout.
// Tambien alimenta el contador de trayecto (suma en el sentido del trayecto, resta al reves) --
// ver manejarDetenida()/manejarMovimiento() para donde se arma/lee/invalida. Por eso esta ISR
// existe siempre, no solo bajo DEBUG_PULSOS (ahi solo esta condicionado el conteo de diagnostico).
static void IRAM_ATTR isrEncA2() {
  ultimoPulsoEncoderISR = millis();
#if DEBUG_PULSOS
  portENTER_CRITICAL_ISR(&muxPulsos);
  pulsosEncA2++;
  portEXIT_CRITICAL_ISR(&muxPulsos);
#endif

  portENTER_CRITICAL_ISR(&muxTrayecto);
  if (trayectoActivo) {
    if (doorStd == sentidoTrayecto) {
      contadorTrayecto++;
    } else {
      contadorTrayecto--;
    }
  }
  portEXIT_CRITICAL_ISR(&muxTrayecto);
}

// ZCROSS: sincroniza el disparo del TRIAC por angulo de fase. Real desde esta sesion (antes era
// solo diagnostico) -- por eso existe siempre, igual que isrEncA2. Antirrebote obligatorio (no
// solo para el conteo): el comparador analogico genera mas de un flanco de subida muy cercano en
// el mismo cruce real, y armar el disparo dos veces por el mismo cruce es justo lo que este
// antirrebote evita.
static void IRAM_ATTR isrZcross() {
  unsigned long ahoraUS = micros();
  if (ahoraUS - tUltimoZcrossUS < ZCROSS_DEBOUNCE_US) return;
  tUltimoZcrossUS = ahoraUS;

#if DEBUG_PULSOS
  portENTER_CRITICAL_ISR(&muxPulsos);
  pulsosZcross++;
  portEXIT_CRITICAL_ISR(&muxPulsos);
#endif

  if (!triacActivo) return;  // motor detenido: no hay nada que disparar

  uint32_t delay = delayDisparoActualUS;  // lectura de 32 bits, atomica en este chip
  esp_timer_stop(timerDisparo);           // por si quedaba uno armado del cruce anterior
  esp_timer_start_once(timerDisparo, delay);
}

#if DEBUG_PULSOS
// Se llama desde loop(). No bloqueante: solo imprime cuando pasaron DEBUG_PULSOS_MS.
void mostrarPulsos() {
  unsigned long ahora = millis();
  if (ahora - tUltimoReportePulsos < DEBUG_PULSOS_MS) return;
  tUltimoReportePulsos = ahora;

  portENTER_CRITICAL(&muxPulsos);
  unsigned long z  = pulsosZcross;
  unsigned long a2 = pulsosEncA2;
  pulsosZcross = 0;
  pulsosEncA2 = 0;
  portEXIT_CRITICAL(&muxPulsos);

  Serial.print("[DIAG] pulsos/");
  Serial.print(DEBUG_PULSOS_MS);
  Serial.print("ms -> ZCROSS=");
  Serial.print(z);
  Serial.print("  ENCA2=");
  Serial.println(a2);
}
#endif
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

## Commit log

2026-08-07 Bootstrap de stele + firmware migrado a PlatformIO (ESP32-S3)
    Instancia el marco stele (layout agrupado, base bitacora/) para dar
    continuidad de documentacion al proyecto. Reestructura Firmware_Porton
    de un sketch .ino a un proyecto PlatformIO (src/main.cpp, src/porton.cpp,
    include/porton.h) para el modulo ESP32-S3-WROOM-1 montado en PCB_puerta,
    sin cambiar el comportamiento original. Incluye el diseno de PCB (KiCad)
    y las referencias/datasheets existentes.
    [BOM-PCB_puerta.csv, HLK-PM01.STEP, HLK-PM01.step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]
2026-08-07 Cierre sesion 002: repo vinculado a origin/main
    Registra en la bitacora la vinculacion del proyecto al repositorio
    Electric_Door_With_ESP32_S3 y el primer commit/push ya realizados.
2026-08-08 Cierre sesion 003: contrato de hardware (pines ESP32-S3 + potencia)
    Documenta el sistema de potencia (motor de fase partida, TRIAC, relevos,
    encoder, finales de carrera, receptor RF) y la tabla completa de pines
    del ESP32-S3 que el usuario entrego como referencia, verificado contra
    el firmware actual. Registra la brecha entre el diseno (ZCROSS/encoder/
    finales de carrera pensados como interrupciones) y la implementacion
    actual (polling / sin usar), como entrada para las decisiones de diseno
    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
2026-08-08 Interlock de seguridad + maquina de estados no bloqueante (sesion 004)
    Reescribe la logica del porton en Firmware_Porton/src/porton.cpp segun
    los requisitos de seguridad del usuario: interlock estructural de reles
    (nunca los dos activos), el motor siempre se detiene antes de invertir
    sentido, deteccion de atasco por timeout de pulsos del encoder (ENCA por
    interrupcion), boton de control remoto por flanco en vez de nivel, y el
    TRIAC tratado como interruptor todo/nada (ZCROSS queda para una sesion
    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
2026-08-08 Cierre sesion 005: confirmaciones de diseno
    Confirma la logica de control remoto (abierta cierra, cerrada abre),
    descarta el conflicto de pines entre TRIGGER (GPIO21) y la UART de
    depuracion (confirmada en GPIO43/44), y registra la decision de
    traducir la documentacion a ingles recien al finalizar el proyecto
    (pool de proyectos open-source de referencia). Sin cambios de codigo.
2026-08-09 Sesion 006: validacion en hardware real, control remoto D0/D2
    Primera sesion con la placa fisica conectada. Corrige un bug de
    comandos por Serial (comando no se limpiaba en los cases '0' y '4').
    Agrega un diagnostico temporal de pulsos (ENCA/ENCB/ZCROSS/ENCA2) que
    permite detectar un problema real de hardware en ENCA/ENCB (pull-up) y
    reemplazarlo por un sensor Hall (ENCA2, GPIO44), confirmado limpio y ya
    promovido a fuente real de deteccion de atasco. Corrige el conteo de
    ZCROSS con antirrebote por software tras confirmar con osciloscopio que
    la senal real es limpia.
    Rediseña el control remoto a pedido del usuario: D0 concentra apertura/
    cierre/inversion/detencion parcial (doble pulsacion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
    [main.cpp, porton.cpp, porton.h]
2026-08-09 Sesion 007: arranque suave del TRIAC por angulo de fase
    Implementa el arranque suave planeado y aprobado con el usuario (plan
    mode): ZCROSS pasa de interrupcion solo-diagnostico a real, disparando
    el gate del TRIAC (BT138-800) por angulo de fase via dos esp_timer en
    cascada (retardo de disparo, ancho de pulso de 200us). Una rampa lineal
    (RAMPA_ARRANQUE_MS) interpola la potencia desde un valor bajo hasta la
    potencia de crucero al iniciar cada movimiento. La parada sigue siendo
    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
2026-08-11 Sesion 008: contador de trayecto, LED, TRIAC en potencia fija (release)
    Agrega contador de trayecto por pulsos de ENCA2 (entre dos finales de
    carrera confirmados, suma/resta segun sentido) e indicador LED
    (encendido en movimiento, parpadeo al confirmar cada fin de carrera).
    Corrige un bug real encontrado en el porton fisico: por inercia del
    motor, el iman de un fin de carrera puede rebasar el sensor al frenar,
    dejando "ningun fin de carrera activo" aunque el porton este
    efectivamente en esa posicion. Se agrega ultimaLlegadaConfirmada para
    decidir el sentido contra la ultima llegada real en vez de asumir
    siempre "cierra por defecto".
    Calibra la potencia del TRIAC en el porton real: disparar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
    [porton.cpp, porton.h]
